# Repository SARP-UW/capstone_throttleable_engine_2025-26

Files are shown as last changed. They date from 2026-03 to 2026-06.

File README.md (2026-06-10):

# capstone_throttleable_engine_2025-26

2025-2026 SARP Capstone Project — a throttleable ethanol / nitrous engine injector testbed.

This repository includes:
- **software** (`software/`) — Python DAQ, valve actuation, throttle control, and web GUI
- **hardware** (`hardware/`) — KiCAD PCB design for DAQ, valve actuation, and servo control
- **analysis** (`analysis/`) — Thermal, structural, and control system analysis 

---

## Software

**Package:** `deep-thrott-code` v0.1.0  
**Requires:** Python ≥ 3.10

### Installation

```bash
pip install -e .
```

### Running the GUI

The system is split into two servers:

| Server | Default address | Role |
|---|---|---|
| **Backend** | `http://0.0.0.0:6001` | DAQ, valve control, F3C sequencer, Socket.IO |
| **GUI** | `http://127.0.0.1:5000` | Serves the web frontend only |

When you open the GUI in a browser, the frontend JS automatically connects to the backend via Socket.IO on port 6001 (same host, different port). The backend streams live sensor data at ~10 Hz and receives commands (valve actuation, sequence control, start/stop logging) from the GUI.

**Running both on the same machine:**

```bash
# Terminal 1 — start the backend
python -m deep_thrott_code.main --host 0.0.0.0 --port 6001

# Terminal 2 — start the GUI server
python -m deep_thrott_code.gui.run_gui --host 0.0.0.0 --port 5000
```

Once the server is running, open any browser on the same network and navigate to:

```
http://<host-ip>:5000
```

If running locally, just go to `http://localhost:5000` or `http://127.0.0.1:5000`.  
If running on a Raspberry Pi, use the Pi's IP address: `http://192.168.x.x:5000`.

**Running backend on a Pi, GUI on your laptop:**

```bash
# On the Pi
python -m deep_thrott_code.main --host 0.0.0.0 --port 6001

# On your laptop (point GUI at the Pi's IP)
python -m deep_thrott_code.gui --backend http://192.168.x.x:6001 --host 127.0.0.1 --port 5000
```

Then open `http://localhost:5000` on your laptop.

**What you see in the browser:**

The GUI is a single-page app with:
- **Line control tabs** — PID diagrams with live valve state and pressure readouts for ethanol and nitrous lines
- **DAQ tabs** — 18 real-time sensor plots (auto-scaled, 300-point history)
- **Sequence panel** — step-by-step fire sequence tracking with manual step execution
- **Settings** — simulation toggle, test selection (hotfire / cold flow), sensor selection, theme

**CLI flags (main backend):**

| Flag | Description |
|---|---|
| `--host` | Bind host (default `0.0.0.0`) |
| `--port` | Bind port (default `6001`) |
| `--simulation` | Run without hardware (sensor simulation) |
| `--no-gui-server` | Start backend only, no Flask server |
| `--autostart` | Automatically start DAQ on launch |
| `--no-sequencer` | Disable the F3C fire sequencer |
| `--debug` | Enable Flask debug mode |

### Structure

```
software/src/deep_thrott_code/
├── main.py               # Entry point
├── backend/              # App factory, GUI command handlers, DAQ runtime
├── gui/                  # Flask + Socket.IO web interface (routes, sockets)
├── daq/                  # Data acquisition — ADC drivers and sensor interfaces
├── f3c/                  # Sequencer and valve control
├── control/              # PID throttle controller and servo characterization
└── config/               # Default configuration files
```

**Utility scripts** (`software/scripts/`):
- `hotfire.py` — Hotfire sequence runner
- `calibrate_sensors.py` — Sensor calibration
- `plot_daq_csv.py` — Plot data from DAQ CSV logs
- `adc_smoke_test.py` — ADC hardware smoke test

### Dependencies

| Package | Purpose |
|---|---|
| Flask, Flask-SocketIO | Web GUI server |
| NumPy, SciPy | Numerical computation |
| PyYAML | Configuration parsing |
| PySerial | Serial communication |
| Matplotlib | Data visualization |
| RPi.GPIO, pigpio, spidev | GPIO and SPI (Linux/RPi only) |
| eventlet *(optional)* | Async server mode |

---

## Hardware

KiCAD project located in `hardware/cda-pcb/`. Includes schematic, PCB layout, Gerber files, and custom symbols/footprints.

---

## Analysis

- `analysis/control_dev/` — Control system models (MATLAB and Python)
- `analysis/engine_dev/` — Structural analysis (Python, based on GRACE methodology)

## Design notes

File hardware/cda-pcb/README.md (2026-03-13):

# High-Precision Raspberry Pi DAQ Board

A custom Data Acquisition (DAQ) hat designed for the Raspberry Pi. This board interfaces with industrial sensors (RTDs, Load Cells, Pressure Transducers) to log and display live data with high precision.

The system features a robust, low-noise power architecture that manages 24VDC input to power the sensors, the precision analog circuitry, and the Raspberry Pi itself. It utilizes dual 24-bit ADCs communicating over SPI for high-resolution signal digitization.

## Features

* **Multi-Sensor Interface:** Three 15-position D-sub connectors for attaching RTDs, Load Cells, and Pressure Transducers.
* **Input Protection:** Every signal line is protected by TVS diode arrays to guard against ESD and surge events.
* **High-Resolution Sampling:** Dual 24-bit ADCs transmit data via SPI to the Raspberry Pi.
* **Low-Noise Power Architecture:**
    * Accepts 24 VDC input.
    * On-board Buck converters for high-efficiency voltage step-down.
    * LDOs and precision voltage references ensure clean power rails for the ADCs and sensors.
    * High-current supply dedicated to the Raspberry Pi.
* **Compact Design:** PCB fits within a 10cm x 10cm footprint to minimize manufacturing costs.

### 3D Rendering
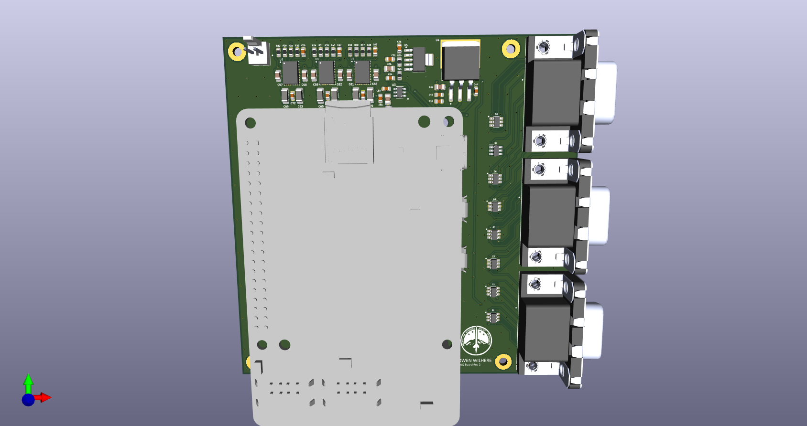
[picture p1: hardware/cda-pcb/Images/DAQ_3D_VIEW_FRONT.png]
Business Card Front


### Layout View
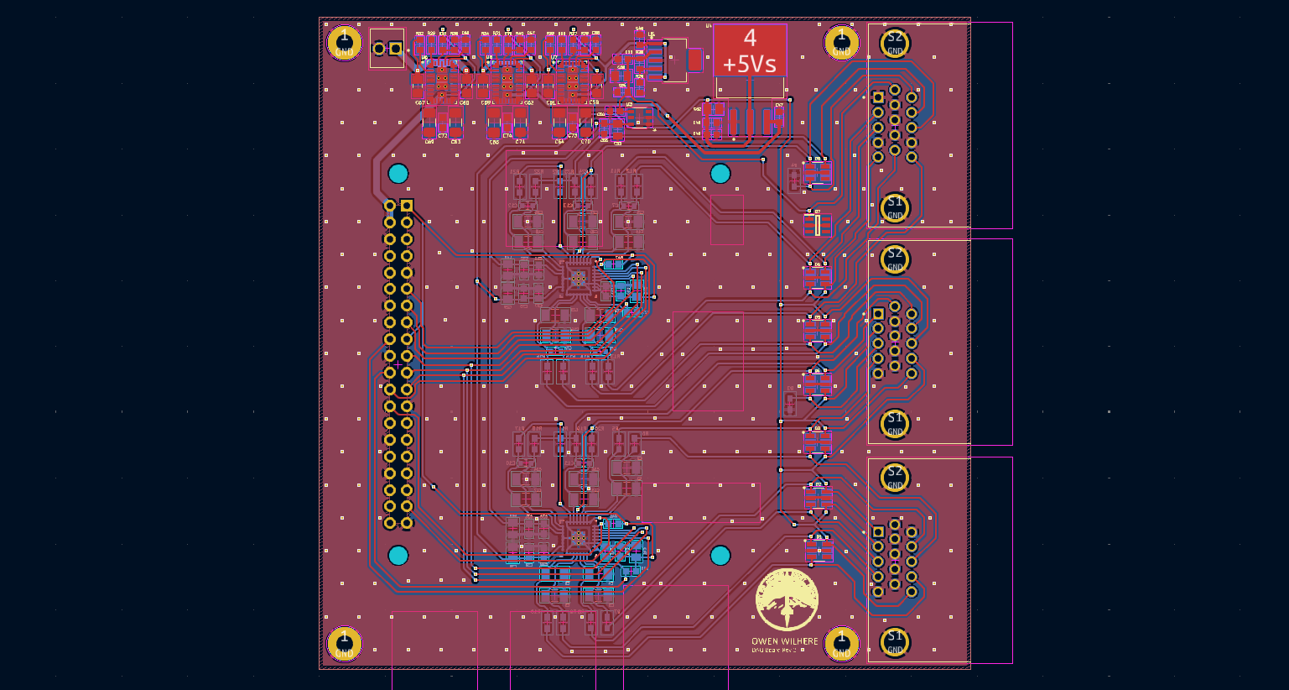
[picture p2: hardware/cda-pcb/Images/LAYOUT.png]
PCB Layout


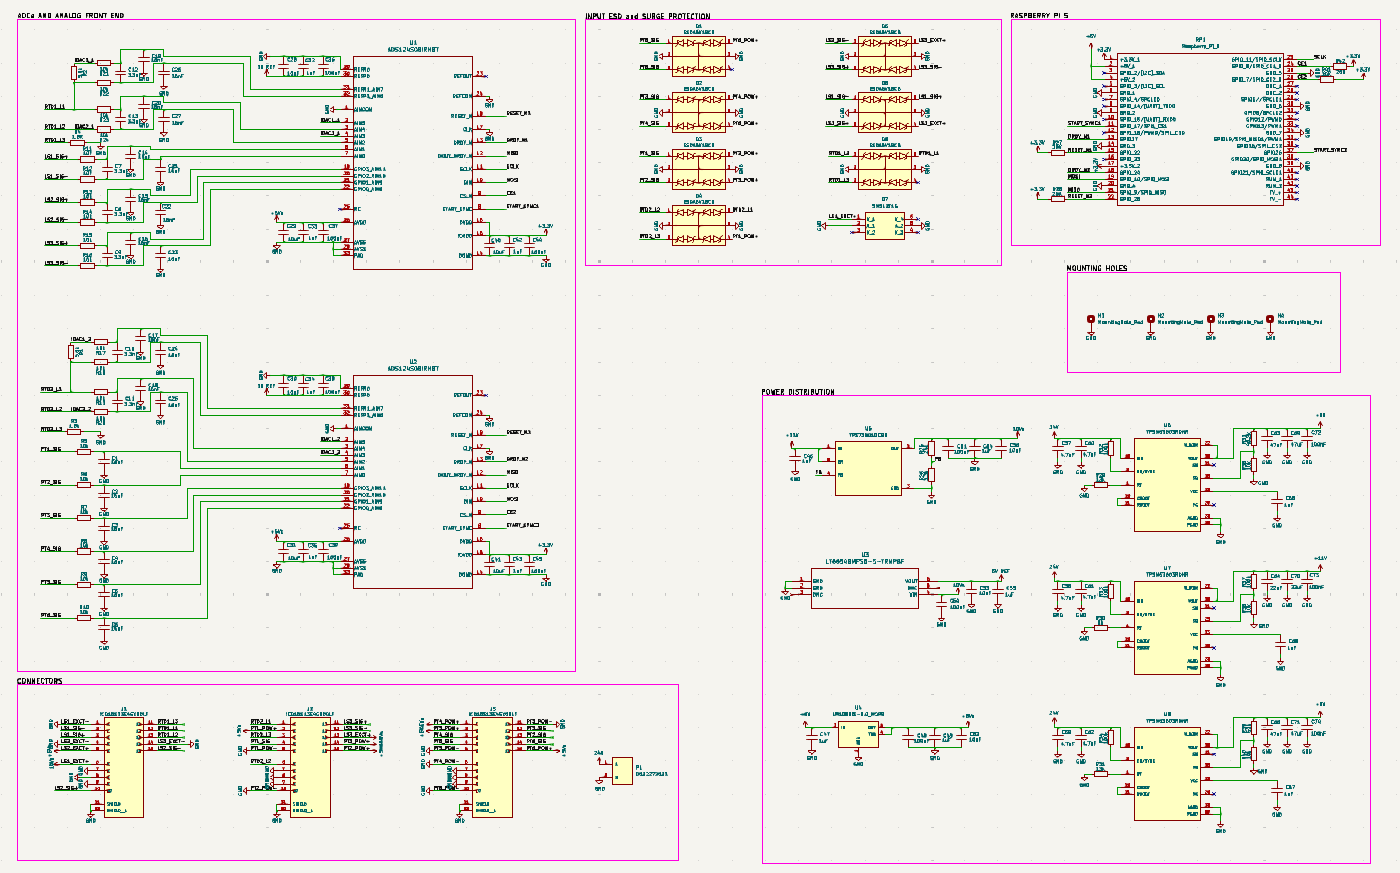
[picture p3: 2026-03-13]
hardware/cda-pcb/Images/SCHEMATIC.png

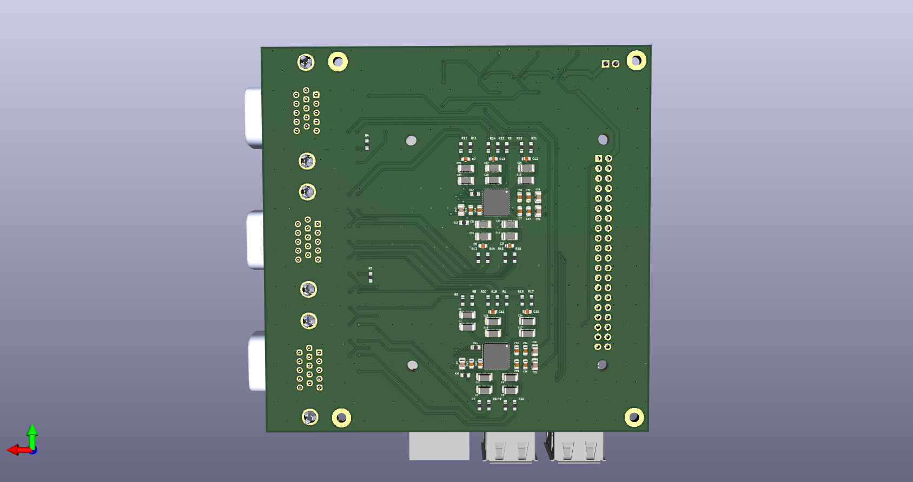
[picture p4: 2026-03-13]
hardware/cda-pcb/Images/DAQ_3D_VIEW_BACK.png

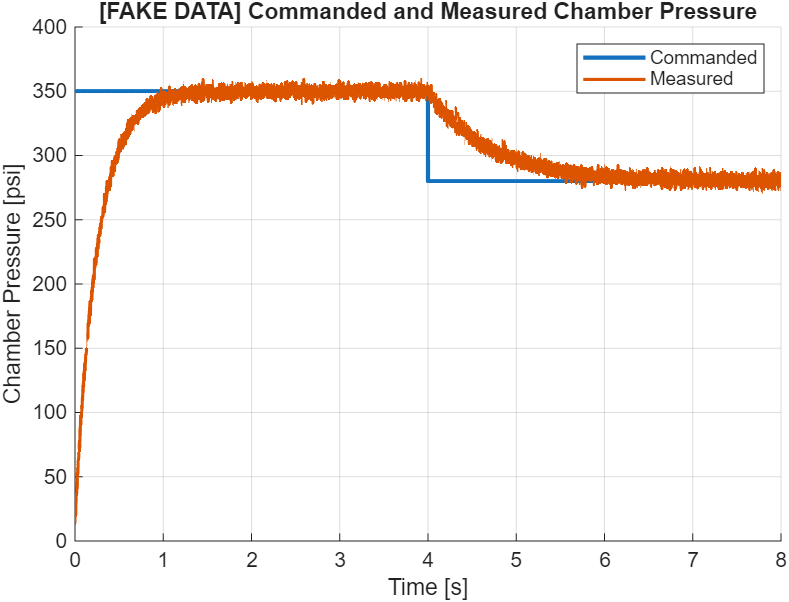
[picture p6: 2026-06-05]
analysis/control_dev/fakedata_conops.png

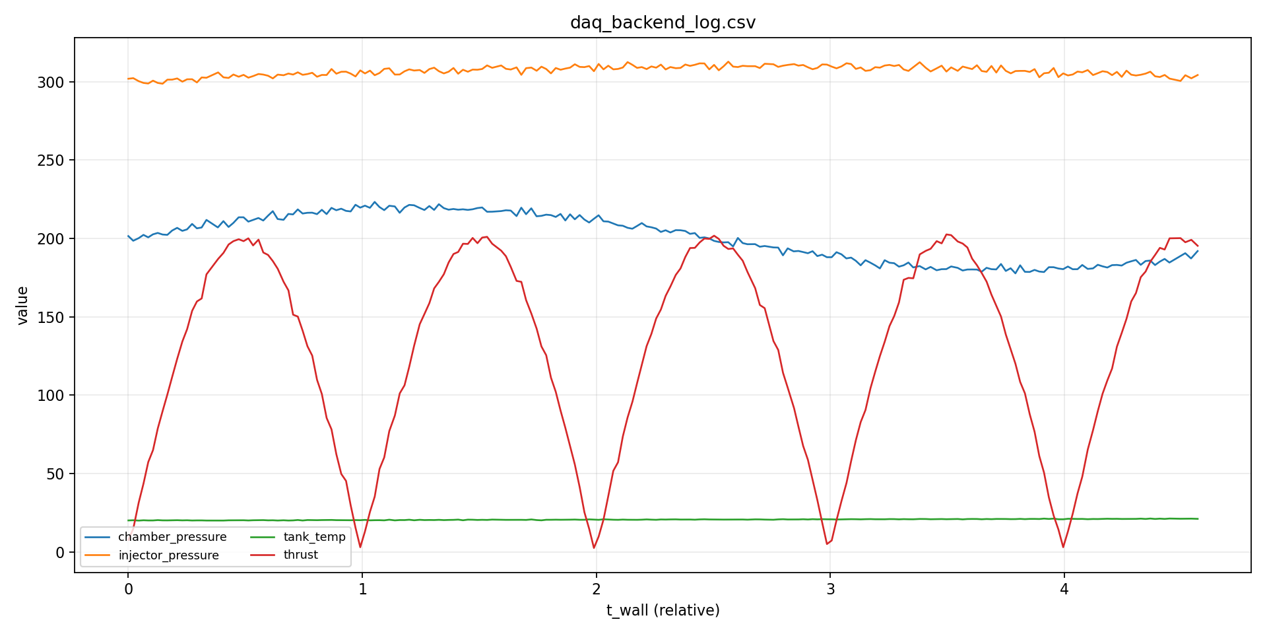
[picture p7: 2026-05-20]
analysis/daq_plot.png

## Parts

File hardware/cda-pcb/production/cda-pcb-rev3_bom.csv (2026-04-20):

Designator | Footprint | Quantity | Value | LCSC Part #
C1, C14, C15, C16, C17, C18, C19, C2, C20, C21, C22, C23, C24, C25, C26, C27, C3, C4, C5, C6, C75, C76, C77, C78, C80, C83, C96, C97, C98, C99 | CAPC3216X95N | 30 | 16nF
C10, C11, C12, C13, C7, C8, C85, C86, C9 | 0603 | 9 | 3.3nF
C28, C29, C30, C31, C40, C41, C52, C53, C56, C87, C88, C93 | CAPC2012X145N | 12 | 10uF
C32, C33, C34, C35, C42, C43, C46, C47, C49, C54, C55, C66, C67, C68, C89, C90, C94 | CAPC1608X94N | 17 | 1uF
C36, C37, C38, C39, C44, C45, C48, C50, C51, C72, C73, C74, C84, C91, C92, C95 | CAPC1608X97N | 16 | 100nF
C57, C58, C59, C60, C61, C62 | 0805 | 6 | 4.7uF
C63, C65, C69, C71 | 1206 | 4 | 47uF
C64, C70 | 1206 | 2 | 22uF
D1, D10, D12, D2, D3, D4, D5, D6, D7, D8, D9 | SOT95P280X145-6N | 11 | ESDA6V1BC6
D11 | SOT95P275X110-6N | 1 | SMS12T1G
D13, D14, D15 | 0805 | 3 | LED
H1, H2, H3, H4 | MountingHole_2.5mm_Pad | 4 | MountingHole_Pad
J1, J2, J3, J4 | AMPHENOL_ICD15S13E4GX00LF | 4 | ICD15S13E4GX00LF
J5 | PinHeader_1x06_P2.54mm_Vertical | 1 | Conn_01x06
P1 | CONN_SD-43650-010_02_MOL | 1 | 436500227
R1, R2, R49, R56 | 0603 | 4 | 5.6k
R10, R11, R12, R13, R14, R15, R16, R17, R18, R19, R20, R21, R22, R23, R24, R44, R45, R46, R47, R48, R5, R55, R58, R59, R6, R60, R61, R7, R8, R9 | 0603 | 30 | 10k
R25, R29, R31 | RESC1508X50N | 3 | 13k
R26 | RESC1508X50N | 1 | 1.8k
R27, R28, R41, R42, R43, R51, R53, R54 | RESC1508X50N | 8 | 20K
R3, R4, R57, R63, R64 | 0603 | 5 | 1.8k
R30 | RESC1508X50N | 1 | 8k
R32, R33, R34, R37 | RESC1508X50N | 4 | 100k
R35 | RESC1508X50N | 1 | 40.2k
R36, R38, R40, R52 | RESC1508X50N | 4 | 10k
R39 | RESC1508X50N | 1 | 50k
RP1 | raspberrypi_2_3 | 1 | Raspberry_Pi_4
U1, U2, U3 | QFN50P500X500X100-33N | 3 | ADS124S08IRHBT
U10 | RGY14_2P05X2P05 | 1 | SN74AHCT125RGYR
U4 | TSOT-23_S6_LIT | 1 | LT6654BMPS6-5-TRMPBF
U5 | TO254P1524X483-4N | 1 | LM1086IS-5.0_NOPB
U6 | SOT127P706X180-6N | 1 | TPS73801DCQR
U7, U8, U9 | CONV_TPSM63602RDHR | 3 | TPSM63603RDHR

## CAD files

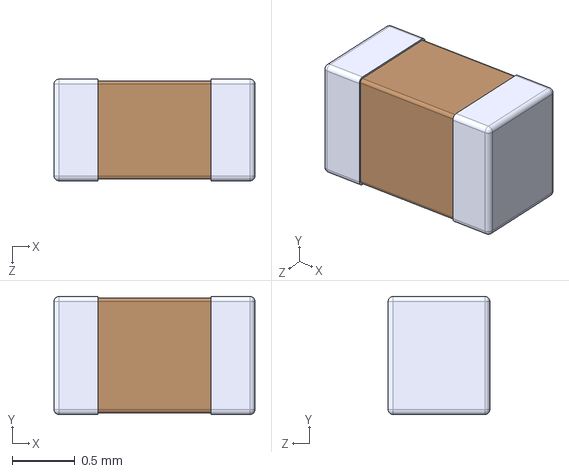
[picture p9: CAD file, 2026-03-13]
hardware/cda-pcb/symbols_and_footprints/0603YC105JAT2A/CAPC1608X94N.step
1.60 x 0.94 x 0.81 mm

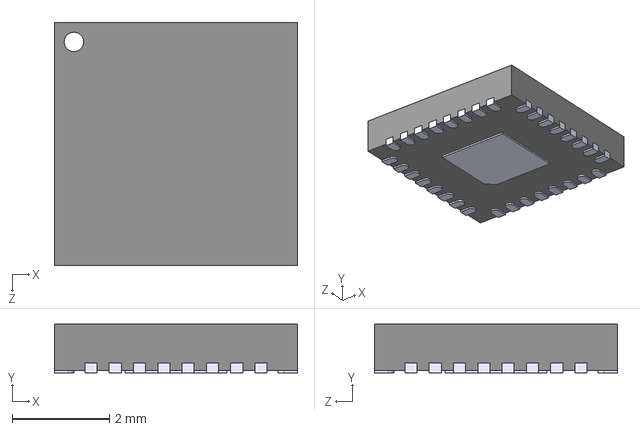
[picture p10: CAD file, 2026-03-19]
hardware/cda-pcb/symbols_and_footprints/ADS124S08IRHBT/ADS124S08IRHBT.step
5.00 x 1.00 x 5.00 mm

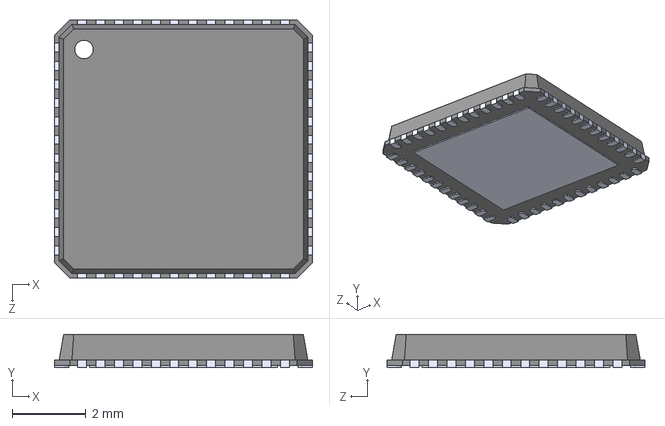
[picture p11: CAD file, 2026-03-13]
hardware/cda-pcb/symbols_and_footprints/ADS1258IRTCT/ADS1258IRTCT.step
7.00 x 0.9 x 7.00 mm

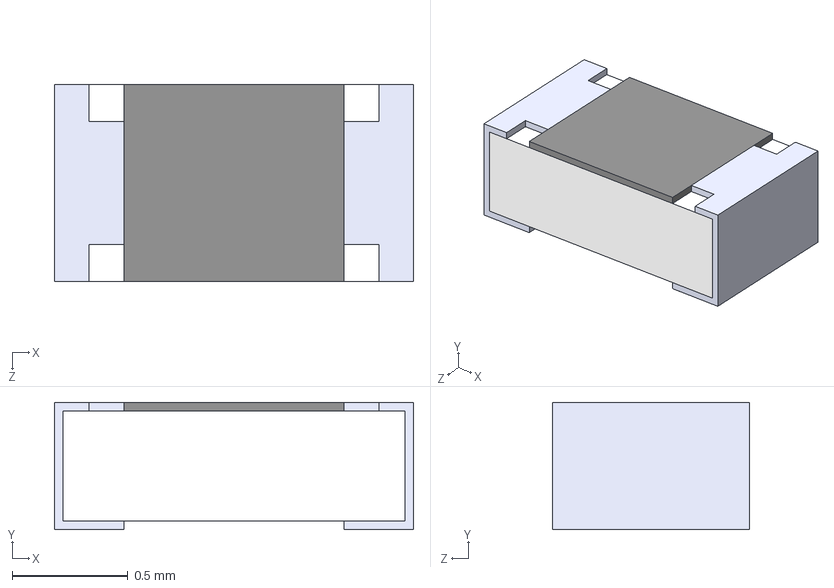
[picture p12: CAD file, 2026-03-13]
hardware/cda-pcb/symbols_and_footprints/CRCW0603100KFKEA/CRCW0603100KFKEA.step
1.55 x 0.55 x 0.85 mm

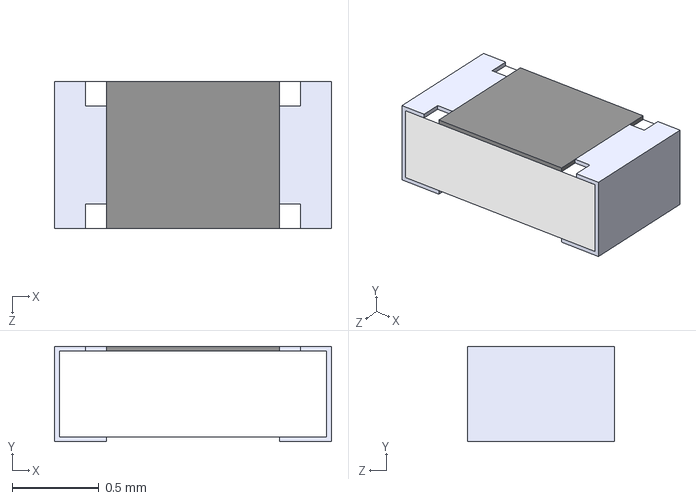
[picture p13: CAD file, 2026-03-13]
hardware/cda-pcb/symbols_and_footprints/CRCW0603120RFKEAHP/CRCW0603120RFKEAHP.step
1.60 x 0.55 x 0.85 mm

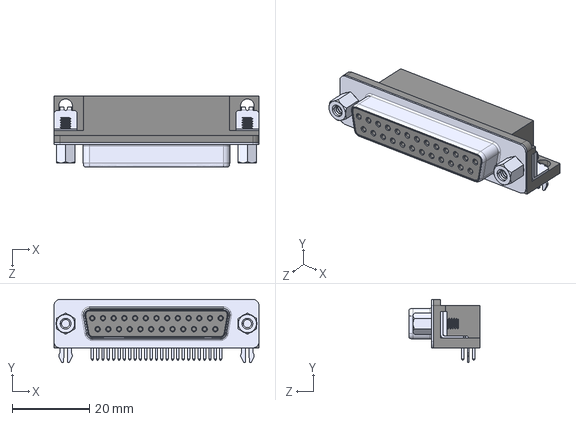
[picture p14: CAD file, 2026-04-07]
hardware/cda-pcb/symbols_and_footprints/DB25_SL_25/DB25-SL-25.step
53.0 x 16.3 x 18.3 mm

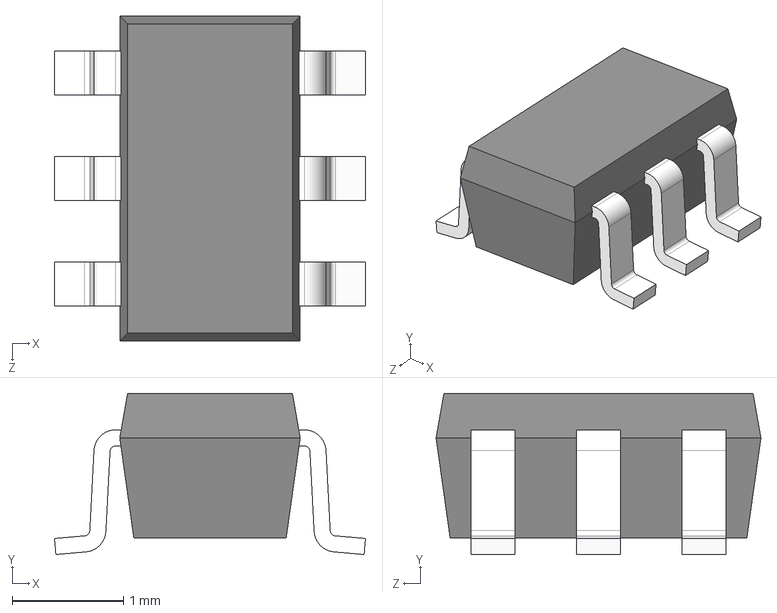
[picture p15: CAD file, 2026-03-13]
hardware/cda-pcb/symbols_and_footprints/ESDA6V1BC6/ESDA6V1BC6.step
2.80 x 1.45 x 2.92 mm

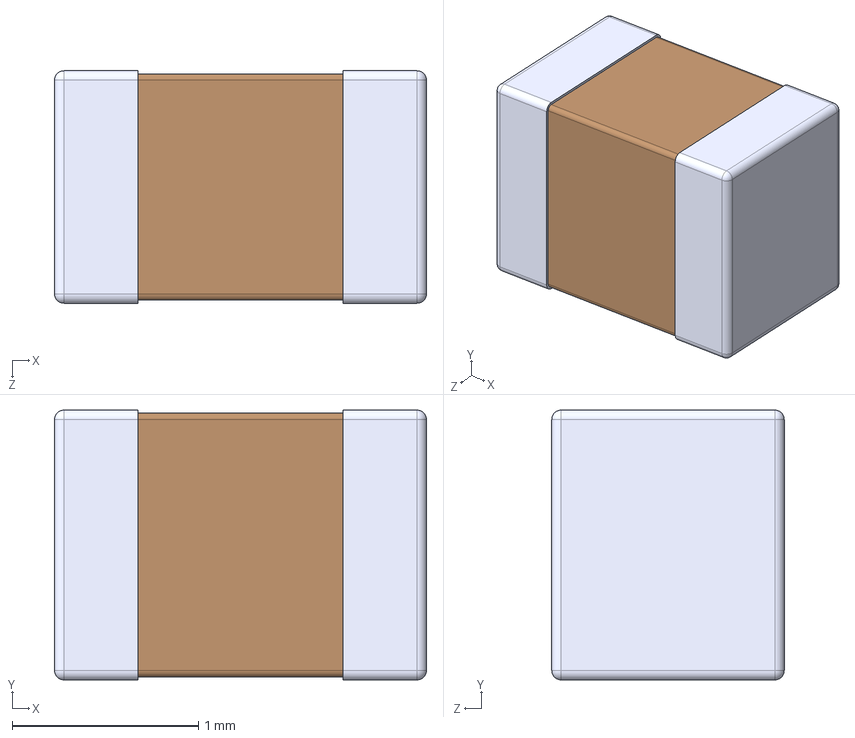
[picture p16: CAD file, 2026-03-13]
hardware/cda-pcb/symbols_and_footprints/GRM21BC71E106KE11L/GRM21BC71E106KE11L.step
2.00 x 1.45 x 1.25 mm

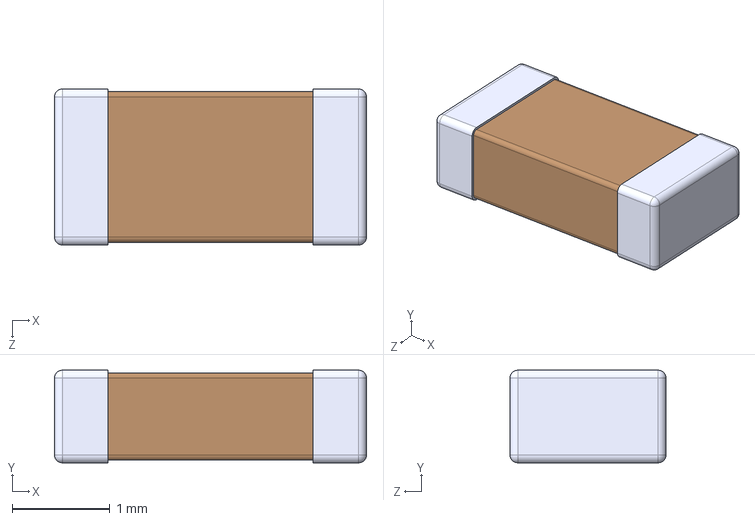
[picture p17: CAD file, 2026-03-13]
hardware/cda-pcb/symbols_and_footprints/GRM3195C2A163JA01D/CAPC3216X95N.step
3.20 x 0.95 x 1.60 mm

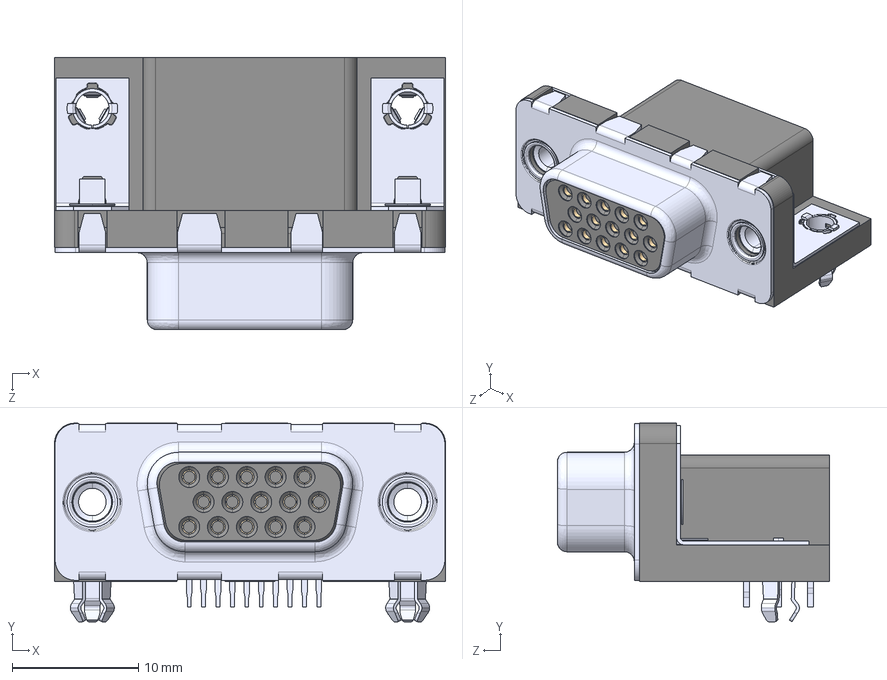
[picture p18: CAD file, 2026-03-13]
hardware/cda-pcb/symbols_and_footprints/ICD15S13/ICD15S13E4GX00LF.step
31.0 x 15.7 x 21.6 mm

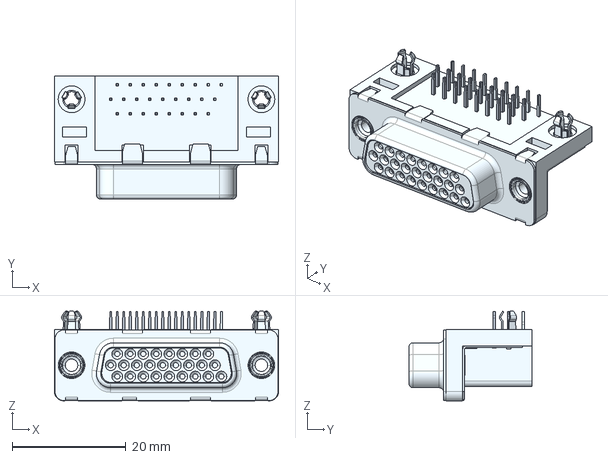
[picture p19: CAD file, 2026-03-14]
hardware/cda-pcb/symbols_and_footprints/ICD26S13E4GX00LF/ICD26S13E4GX00LF.step
39.3 x 21.6 x 15.8 mm

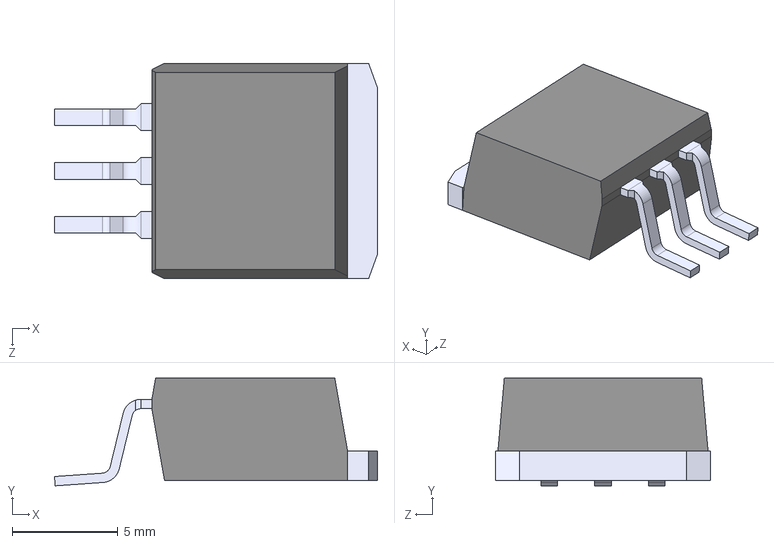
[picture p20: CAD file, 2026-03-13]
hardware/cda-pcb/symbols_and_footprints/LM1086IS-5.0/LM1086IS-5.0.step
15.2 x 5.08 x 10.2 mm

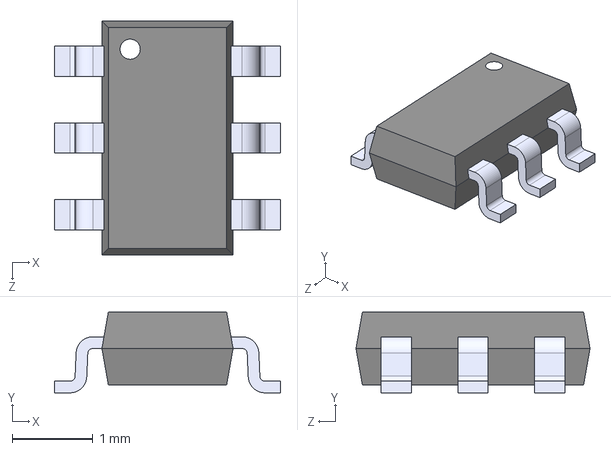
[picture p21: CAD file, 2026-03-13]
hardware/cda-pcb/symbols_and_footprints/LT6654BMPS6_5_TRMPBF/LT6654BMPS6-5#TRPBF.STEP
2.80 x 1.00 x 2.90 mm

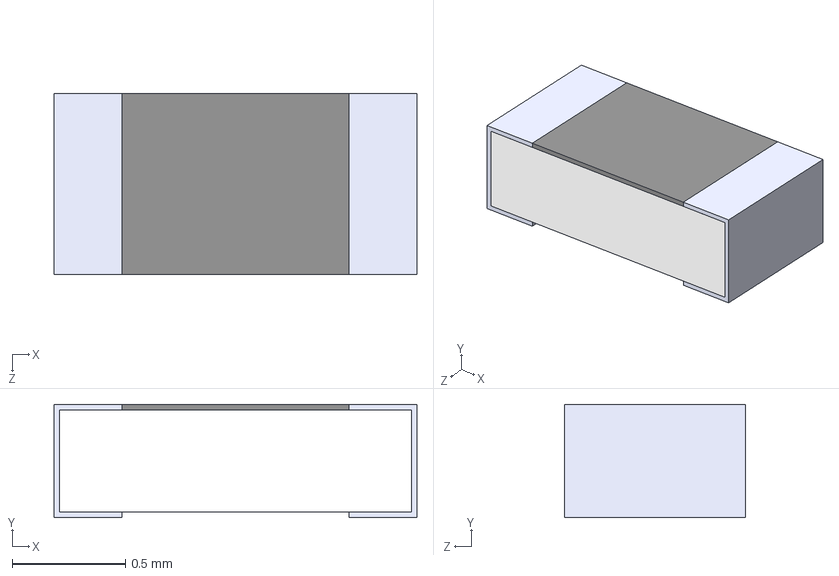
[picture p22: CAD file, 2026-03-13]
hardware/cda-pcb/symbols_and_footprints/RG1608N-102-D-T5/RG1608N-102-D-T5.step
1.60 x 0.5 x 0.8 mm

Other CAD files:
hardware/cda-pcb/symbols_and_footprints/SEN-13879/SEN-13879.step
hardware/cda-pcb/symbols_and_footprints/SMST12T1G/SMS12T1G.STEP
hardware/cda-pcb/symbols_and_footprints/TPSM63602RDHDR/TPSM63602RDHR.step
hardware/cda-pcb/symbols_and_footprints/0022272021/0022272021.step
hardware/cda-pcb/symbols_and_footprints/10090929-S154VLF/10090929-S154VLF.step
hardware/cda-pcb/symbols_and_footprints/436500227/436500227.stp
hardware/cda-pcb/symbols_and_footprints/TPS73801/TPS73801DCQR.step
hardware/cda-pcb/symbols_and_footprints/VJ0603Y104JXXAC/VJ0603Y104JXXAC.step

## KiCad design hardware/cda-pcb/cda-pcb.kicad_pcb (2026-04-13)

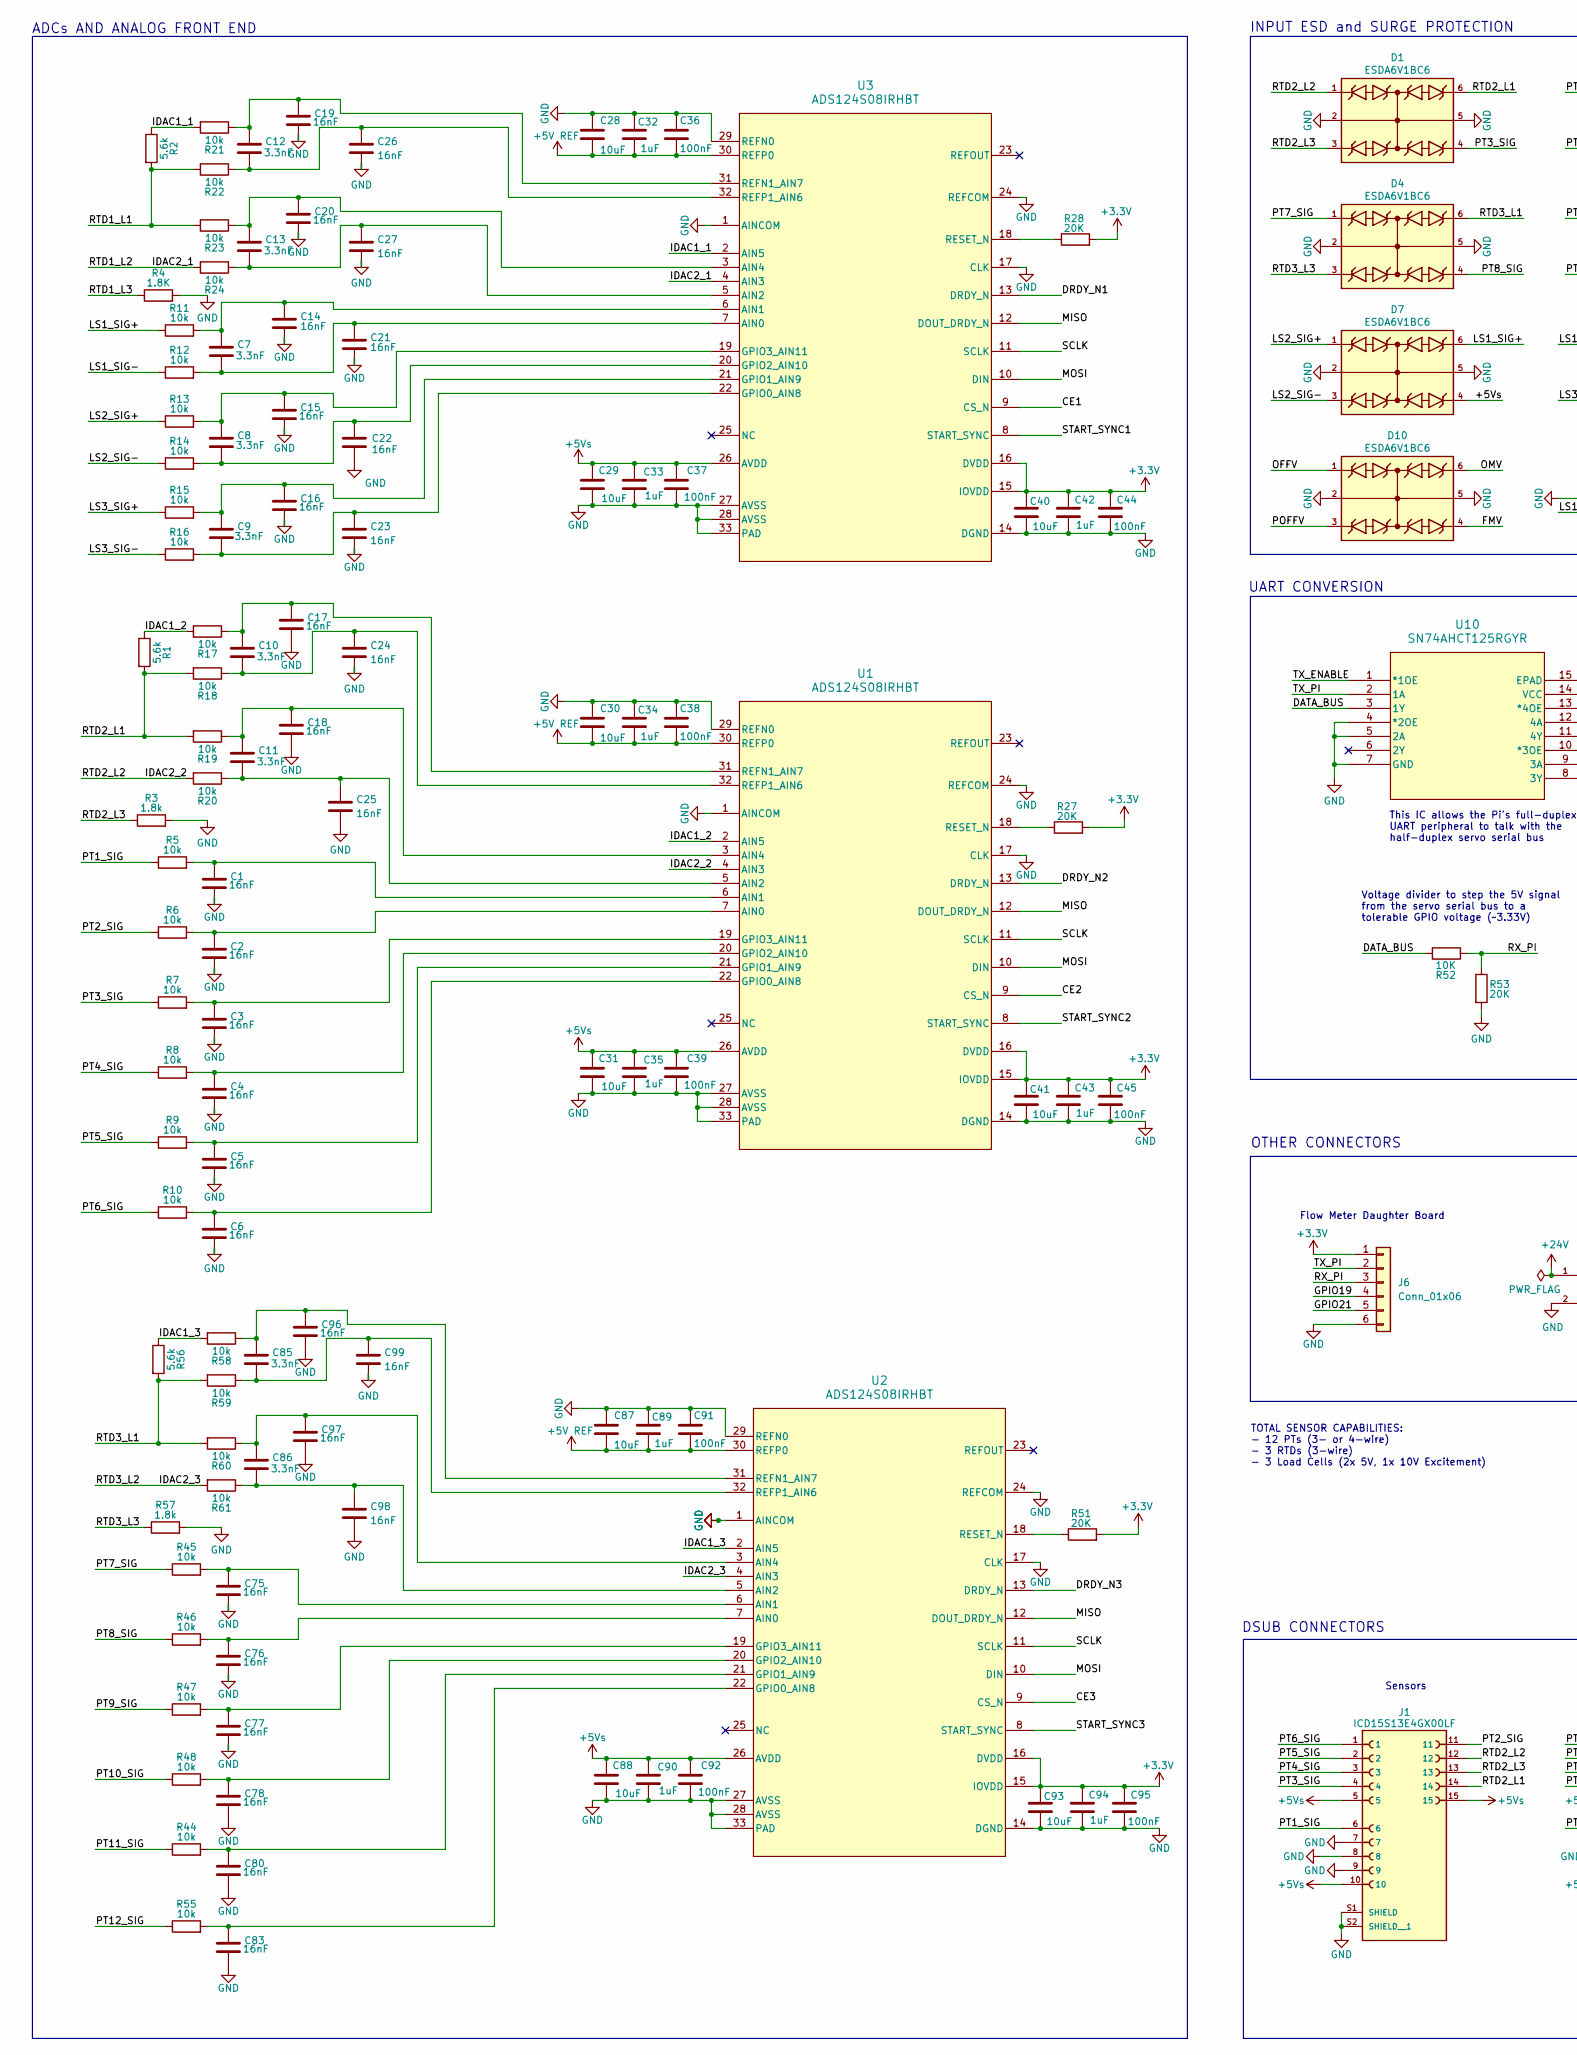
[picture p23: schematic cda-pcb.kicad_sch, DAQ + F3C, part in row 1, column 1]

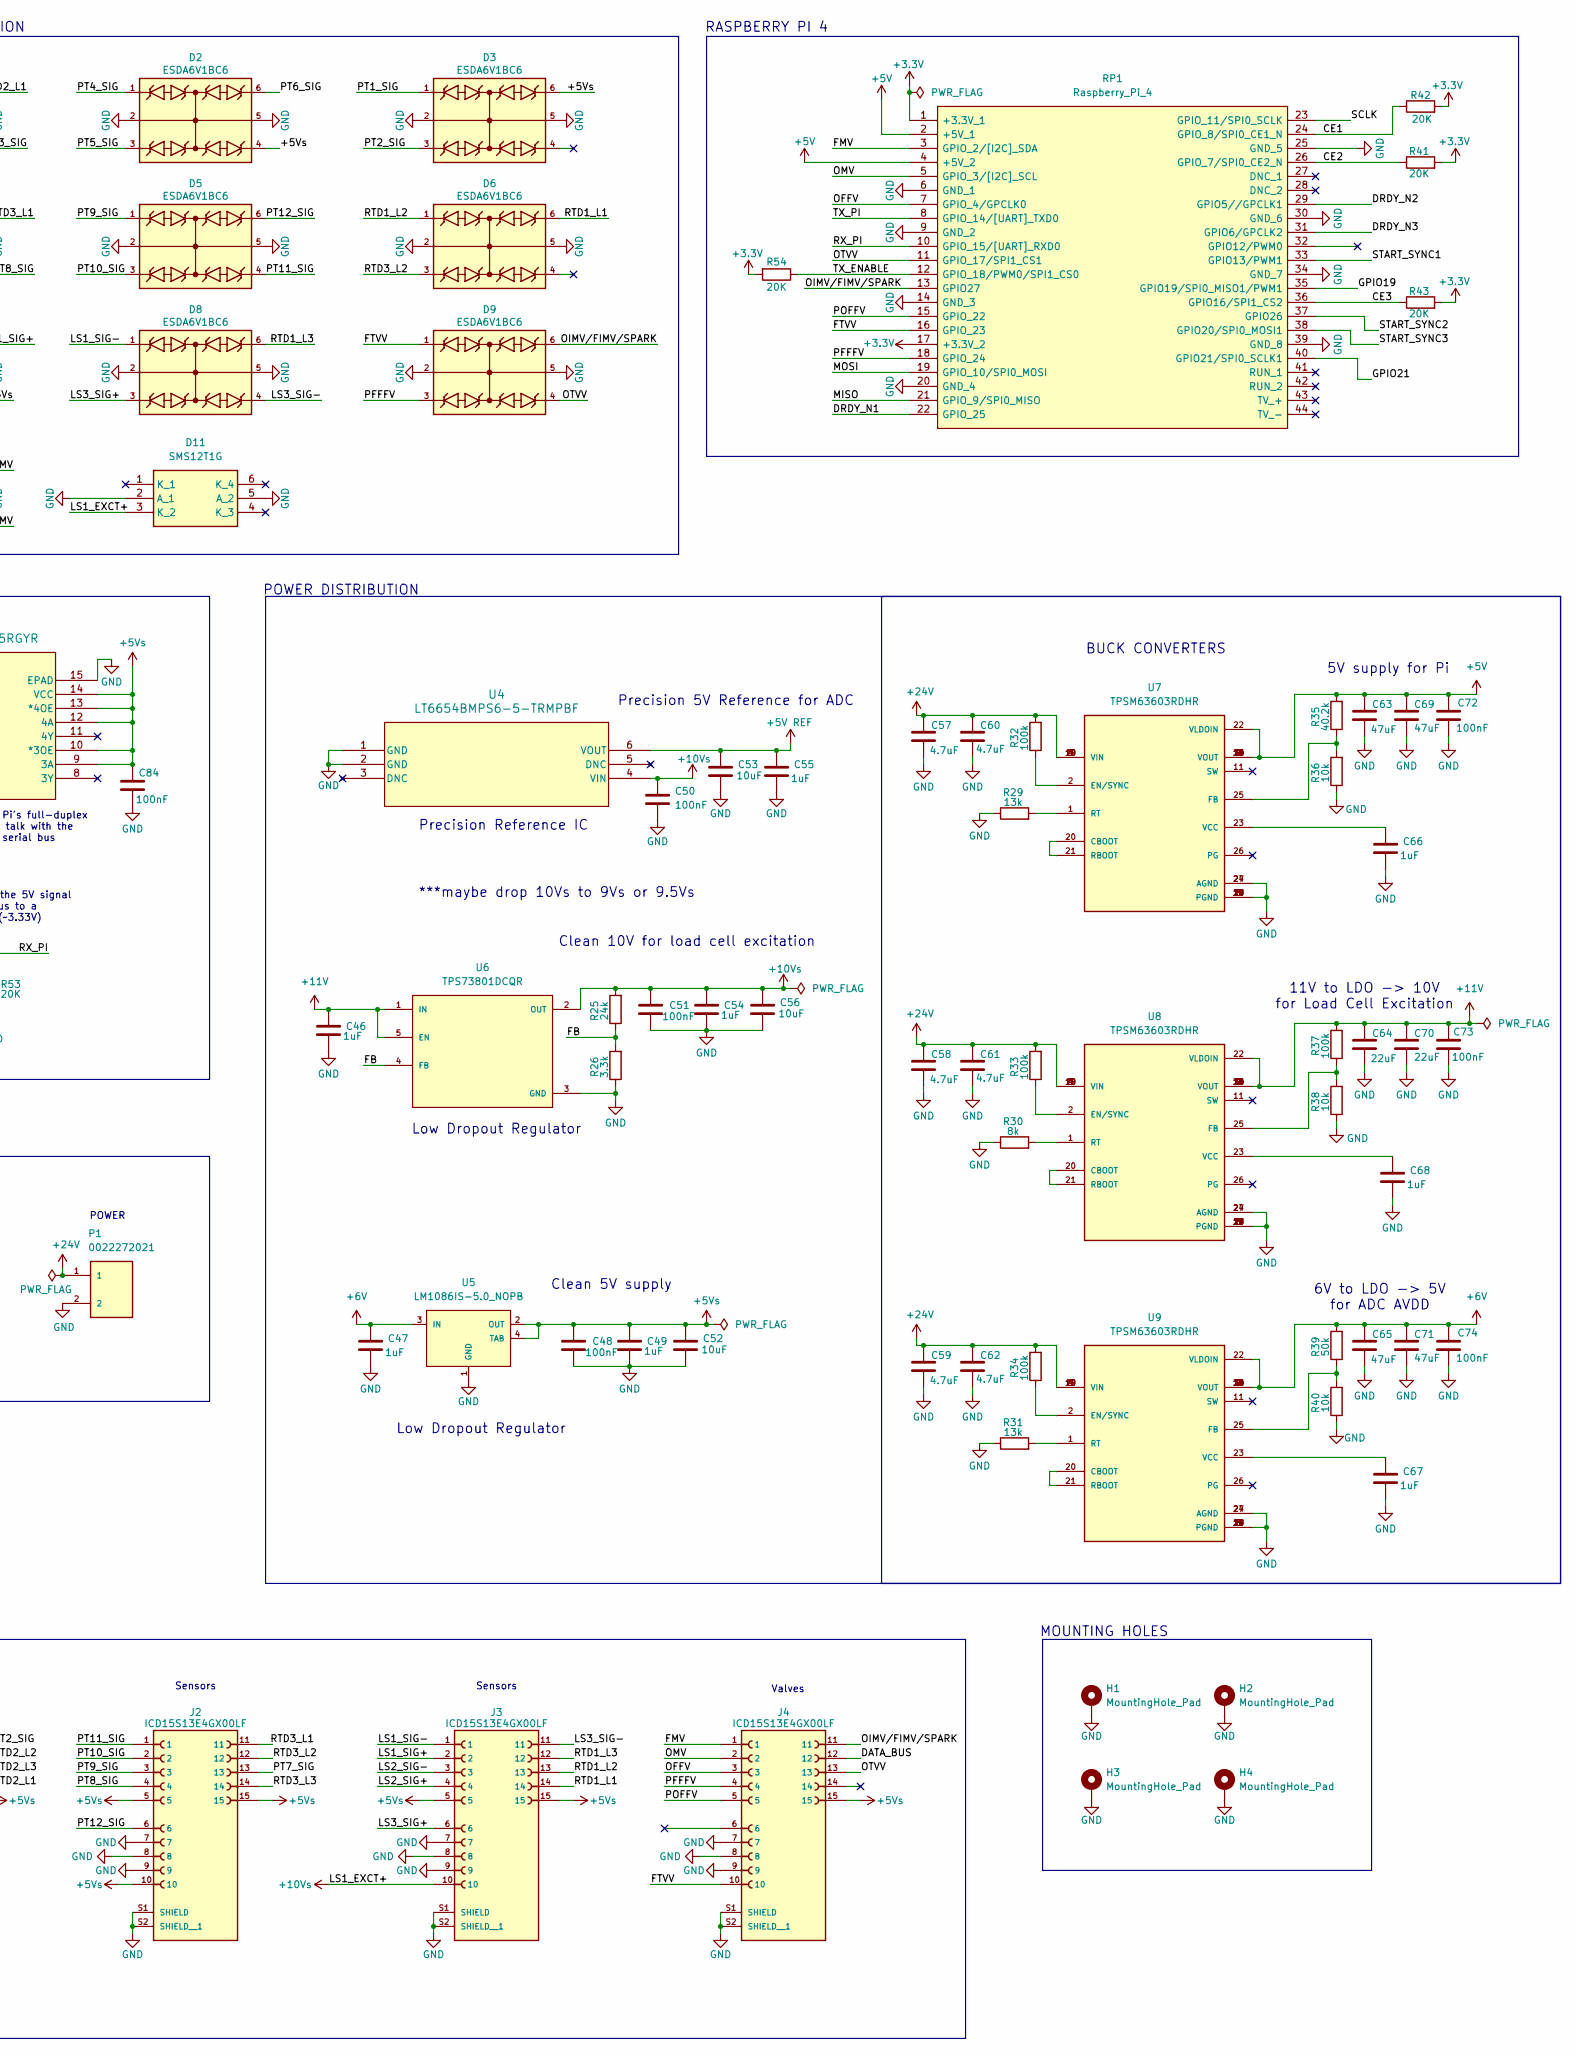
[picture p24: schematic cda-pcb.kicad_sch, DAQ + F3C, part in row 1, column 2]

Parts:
C1, C2, C3, C4, C5, C6, C14, C15, C16, C17, C18, C19, C20, C21, C22, C23, C24, C25, C26, C27, C75, C76, C77, C78, C80, C83, C96, C97, C98, C99: 16nF; CAPC3216X95N
C7, C8, C9, C10, C11, C12, C13, C85, C86: 3.3nF; C_0603_1608Metric_Pad1.08x0.95mm_HandSolder
C28, C29, C30, C31, C40, C41, C52, C53, C56, C87, C88, C93: 10uF; CAPC2012X145N
C32, C33, C34, C35, C42, C43, C46, C47, C49, C54, C55, C66, C67, C68, C89, C90, C94: 1uF; CAPC1608X94N
C36, C37, C38, C39, C44, C45, C48, C50, C51, C72, C73, C74, C84, C91, C92, C95: 100nF; CAPC1608X97N
C57, C58, C59, C60, C61, C62: 4.7uF; C_0805_2012Metric_Pad1.18x1.45mm_HandSolder
C63, C65, C69, C71: 47uF; L_1206_3216Metric_Pad1.42x1.75mm_HandSolder
C64, C70: 22uF; L_1206_3216Metric_Pad1.42x1.75mm_HandSolder
D1, D2, D3, D4, D5, D6, D7, D8, D9, D10: ESDA6V1BC6; SOT95P280X145-6N; PARTREV 2
D11: SMS12T1G; SOT95P275X110-6N; Manufacturer_Part_Number SMS12T1G; Mouser Part Number 863-SMS12T1G
H1, H2, H3, H4: MountingHole_Pad; MountingHole_2.5mm_Pad
J1, J2, J3, J4: ICD15S13E4GX00LF; AMPHENOL_ICD15S13E4GX00LF; PARTREV G
J6: Conn_01x06; PinHeader_1x06_P2.54mm_Vertical
P1: 0022272021; MOLEX_0022272021
R1, R2, R56: 5.6k; R_0603_1608Metric
R3, R57: 1.8k; R_0603_1608Metric
R4: 1.8K; R_0603_1608Metric
R5, R6, R7, R8, R9, R10, R11, R12, R13, R14, R15, R16, R17, R18, R19, R20, R21, R22, R23, R24, R44, R45, R46, R47, R48, R55, R58, R59, R60, R61: 10k; R_0603_1608Metric
R25: 24k; RESC1508X50N
R26: 3.3k; RESC1508X50N
R27, R28, R41, R42, R43, R51, R53, R54: 20K; RESC1508X50N
R29, R31: 13k; RESC1508X50N
R30: 8k; RESC1508X50N
R32, R33, R34, R37: 100k; RESC1508X50N
R35: 40.2k; RESC1508X50N
R36, R38, R40: 10k; RESC1508X50N
R39: 50k; RESC1508X50N
R52: 10K; RESC1508X50N
RP1: Raspberry_Pi_4; raspberrypi_2_3; Manufacturer_Part_Number Raspberry Pi 2 or 3
U1, U2: ADS124S08IRHBT; QFN50P500X500X100-33N
U3: ADS124S08IRHBT; RHB0032M
U4: LT6654BMPS6-5-TRMPBF; TSOT-23_S6_LIT
U5: LM1086IS-5.0_NOPB; TO254P1524X483-4N
U6: TPS73801DCQR; SOT127P706X180-6N
U7, U8, U9: TPSM63603RDHR; CONV_TPSM63602RDHR; PARTREV April 2022
U10: SN74AHCT125RGYR; RGY14_2P05X2P05

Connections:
+3.3V: C40.1, C41.1, C42.1, C43.1, C44.1, C45.1, C93.1, C94.1, C95.1, J6.1, R27.2, R28.2, R41.2, R42.2, R43.2, R51.2, R54.2, RP1.1 (+3.3V_1), RP1.17 (+3.3V_2), U1.15 (IOVDD), U1.16 (DVDD), U2.15 (IOVDD), U2.16 (DVDD), U3.15 (IOVDD), U3.16 (DVDD)
+5V: C63.2, C69.2, C72.1, R35.2, RP1.2 (+5V_1), RP1.4 (+5V_2), U7.7 (VOUT), U7.8 (VOUT), U7.9 (VOUT), U7.10 (VOUT), U7.12 (VOUT), U7.13 (VOUT), U7.14 (VOUT), U7.15 (VOUT), U7.22 (VLDOIN), U7.30 (VOUT)
+5V REF: C28.2, C30.2, C32.2, C34.2, C36.2, C38.2, C53.1, C55.1, C87.2, C89.2, C91.2, U1.30 (REFP0), U2.30 (REFP0), U3.30 (REFP0), U4.6 (VOUT)
+5Vs: C29.1, C31.1, C33.1, C35.1, C37.1, C39.1, C48.1, C49.1, C52.1, C84.1, C88.1, C90.1, C92.1, D2.4, D3.6, D7.4, J1.5, J1.10, J1.15, J2.5, J2.10, J2.15, J3.5, J3.15, J4.15, U1.26 (AVDD), U2.26 (AVDD), U3.26 (AVDD), U5.2 (OUT), U5.4 (TAB), U10.9 (3A), U10.10 (*3OE), U10.12 (4A), U10.13 (*4OE), U10.14 (VCC)
+6V: C47.1, C65.2, C71.2, C74.1, R39.2, U5.3 (IN), U9.7 (VOUT), U9.8 (VOUT), U9.9 (VOUT), U9.10 (VOUT), U9.12 (VOUT), U9.13 (VOUT), U9.14 (VOUT), U9.15 (VOUT), U9.22 (VLDOIN), U9.30 (VOUT), U9.31
+10Vs: C50.1, C51.1, C54.1, C56.1, D11.3 (K_2), J3.10, R25.2, U4.4 (VIN), U6.2 (OUT)
+11V: C46.1, C64.2, C70.2, C73.1, R37.2, U6.1 (IN), U6.5 (EN), U8.7 (VOUT), U8.8 (VOUT), U8.9 (VOUT), U8.10 (VOUT), U8.12 (VOUT), U8.13 (VOUT), U8.14 (VOUT), U8.15 (VOUT), U8.22 (VLDOIN), U8.30 (VOUT), U8.31
+24V: C57.2, C58.2, C59.2, C60.2, C61.2, C62.2, P1.1, R32.2, R33.2, R34.2, U7.3 (VIN), U7.4 (VIN), U7.18 (VIN), U7.19 (VIN), U8.3 (VIN), U8.4 (VIN), U8.18 (VIN), U8.19 (VIN), U9.3 (VIN), U9.4 (VIN), U9.18 (VIN), U9.19 (VIN)
/CE1: R42.1, RP1.24 (GPIO_8/SPI0_CE1_N), U3.9 (CS_N)
/CE2: R41.1, RP1.26 (GPIO_7/SPI0_CE2_N), U1.9 (CS_N)
/CE3: R43.1, RP1.36 (GPIO16/SPI1_CS2), U2.9 (CS_N)
/DATA_BUS: J4.12, R52.2, U10.3 (1Y)
/DRDY_N1: RP1.22 (GPIO_25), U3.13 (DRDY_N)
/DRDY_N2: RP1.29 (GPIO5//GPCLK1), U1.13 (DRDY_N)
/DRDY_N3: RP1.31 (GPIO6/GPCLK2), U2.13 (DRDY_N)
/FB: R25.1, R26.2, U6.4 (FB)
/FMV: D10.4, J4.1, RP1.3 (GPIO_2/[I2C]_SDA)
/FTVV: D9.1, J4.10, RP1.16 (GPIO_23)
/GPIO19: J6.4, RP1.35 (GPIO19/SPI0_MISO1/PWM1)
/GPIO21: J6.5, RP1.40 (GPIO21/SPI0_SCLK1)
/IDAC1_1: R2.1, R21.2, U3.2 (AIN5)
/IDAC1_2: R1.1, R17.2, U1.2 (AIN5)
/IDAC1_3: R56.1, R58.2, U2.2 (AIN5)
/IDAC2_1: D6.1, J3.13, R24.2, U3.4 (AIN3)
/IDAC2_2: D1.1, J1.12, R20.2, U1.4 (AIN3)
/IDAC2_3: D6.3, J2.12, R61.2, U2.4 (AIN3)
/LS1_SIG+: D7.6, J3.2, R11.1
/LS1_SIG-: D8.1, J3.1, R12.1
/LS2_SIG+: D7.1, J3.4, R13.1
/LS2_SIG-: D7.3, J3.3, R14.1
/LS3_SIG+: D8.3, J3.6, R15.1
/LS3_SIG-: D8.4, J3.11, R16.1
/MISO: RP1.21 (GPIO_9/SPI0_MISO), U1.12 (DOUT_DRDY_N), U2.12 (DOUT_DRDY_N), U3.12 (DOUT_DRDY_N)
/MOSI: RP1.19 (GPIO_10/SPI0_MOSI), U1.10 (DIN), U2.10 (DIN), U3.10 (DIN)
/OFFV: D10.1, J4.3, RP1.7 (GPIO_4/GPCLK0)
/OIMV/FIMV/SPARK: D9.6, J4.11, RP1.13 (GPIO27)
/OMV: D10.6, J4.2, RP1.5 (GPIO_3/[I2C]_SCL)
/OTVV: D9.4, J4.13, RP1.11 (GPIO_17/SPI1_CS1)
/PFFFV: D9.3, J4.4, RP1.18 (GPIO_24)
/POFFV: D10.3, J4.5, RP1.15 (GPIO_22)
/PT1_SIG: D3.1, J1.6, R5.1
/PT2_SIG: D3.3, J1.11, R6.1
/PT3_SIG: D1.4, J1.4, R7.1
/PT4_SIG: D2.1, J1.3, R8.1
/PT5_SIG: D2.3, J1.2, R9.1
/PT6_SIG: D2.6, J1.1, R10.1
/PT7_SIG: D4.1, J2.13, R45.1
/PT8_SIG: D4.4, J2.4, R46.1
/PT9_SIG: D5.1, J2.3, R47.1
/PT10_SIG: D5.3, J2.2, R48.1
/PT11_SIG: D5.4, J2.1, R44.1
/PT12_SIG: D5.6, J2.6, R55.1
/RTD1_L1: D6.6, J3.14, R2.2, R22.2, R23.2
/RTD1_L3: D8.6, J3.12, R4.1
/RTD2_L1: D1.6, J1.14, R1.2, R18.2, R19.2
/RTD2_L3: D1.3, J1.13, R3.1
/RTD3_L1: D4.6, J2.11, R56.2, R59.2, R60.2
/RTD3_L3: D4.3, J2.14, R57.1
/RX_PI: J6.3, R52.1, R53.1, RP1.10 (GPIO_15/[UART]_RXD0)
/SCLK: RP1.23 (GPIO_11/SPI0_SCLK), U1.11 (SCLK), U2.11 (SCLK), U3.11 (SCLK)
/START_SYNC1: RP1.33 (GPIO13/PWM1), U3.8 (START_SYNC)
/START_SYNC2: RP1.37 (GPIO26), U1.8 (START_SYNC)
/START_SYNC3: RP1.38 (GPIO20/SPI0_MOSI1), U2.8 (START_SYNC)
/TX_ENABLE: R54.1, RP1.12 (GPIO_18/PWM0/SPI1_CS0), U10.1 (*1OE)
/TX_PI: J6.2, RP1.8 (GPIO_14/[UART]_TXD0), U10.2 (1A)
GND: C1.2, C2.2, C3.2, C4.2, C5.2, C6.2, C14.2, C15.2, C16.2, C17.2, C18.2, C19.2, C20.2, C21.2, C22.2, C23.2, C24.2, C25.2, C26.2, C27.2, C28.1, C29.2, C30.1, C31.2, C32.1, C33.2, C34.1, C35.2, C36.1, C37.2, C38.1, C39.2, C40.2, C41.2, C42.2, C43.2, C44.2, C45.2, C46.2, C47.2, C48.2, C49.2, C50.2, C51.2, C52.2, C53.2, C54.2, C55.2, C56.2, C57.1, C58.1, C59.1, C60.1, C61.1, C62.1, C63.1, C64.1, C65.1, C66.2, C67.2, C68.2, C69.1, C70.1, C71.1, C72.2, C73.2, C74.2, C75.2, C76.2, C77.2, C78.2, C80.2, C83.2, C84.2, C87.1, C88.2, C89.1, C90.2, C91.1, C92.2, C93.2, C94.2, C95.2, C96.2, C97.2, C98.2, C99.2, D1.2, D1.5, D2.2, D2.5, D3.2, D3.5, D4.2, D4.5, D5.2, D5.5, D6.2, D6.5, D7.2, D7.5, D8.2, D8.5, D9.2, D9.5, D10.2, D10.5, D11.2 (A_1), D11.5 (A_2), H1.1, H2.1, H3.1, H4.1, J1.7, J1.8, J1.9, J1.S1 (SHIELD), J1.S2 (SHIELD__1), J2.7, J2.8, J2.9, J2.S1 (SHIELD), J2.S2 (SHIELD__1), J3.7, J3.8, J3.9, J3.S1 (SHIELD), J3.S2 (SHIELD__1), J4.7, J4.8, J4.9, J4.S1 (SHIELD), J4.S2 (SHIELD__1), J6.6, P1.2, R3.2, R4.2, R26.1, R29.1, R30.1, R31.1, R36.1, R38.1, R40.1, R53.2, R57.2, RP1.6 (GND_1), RP1.9 (GND_2), RP1.14 (GND_3), RP1.20 (GND_4), RP1.25 (GND_5), RP1.30 (GND_6), RP1.34 (GND_7), RP1.39 (GND_8), U1.1 (AINCOM), U1.14 (DGND), U1.17 (CLK), U1.24 (REFCOM), U1.27 (AVSS), U1.28 (AVSS), U1.29 (REFN0), U1.33 (PAD), U2.1 (AINCOM), U2.14 (DGND), U2.17 (CLK), U2.24 (REFCOM), U2.27 (AVSS), U2.28 (AVSS), U2.29 (REFN0), U2.33 (PAD), U3.1 (AINCOM), U3.14 (DGND), U3.17 (CLK), U3.24 (REFCOM), U3.27 (AVSS), U3.28 (AVSS), U3.29 (REFN0), U3.33 (PAD), U4.1 (GND), U4.2 (GND), U5.1 (GND), U6.3 (GND), U7.5 (PGND), U7.6 (PGND), U7.16 (PGND), U7.17 (PGND), U7.24 (AGND), U7.27 (AGND), U7.28 (PGND), U7.29 (PGND), U7.32, U7.35, U7.36, U8.5 (PGND), U8.6 (PGND), U8.16 (PGND), U8.17 (PGND), U8.24 (AGND), U8.27 (AGND), U8.28 (PGND), U8.29 (PGND), U8.32, U8.35, U8.36, U9.5 (PGND), U9.6 (PGND), U9.16 (PGND), U9.17 (PGND), U9.24 (AGND), U9.27 (AGND), U9.28 (PGND), U9.29 (PGND), U9.32, U9.35, U9.36, U10.4 (*2OE), U10.5 (2A), U10.7 (GND), U10.15 (EPAD)
unnamed: C2.1, R6.2, U1.7 (AIN0)
unnamed: C1.1, R5.2, U1.6 (AIN1)
unnamed: C11.2, C25.1, R20.1, U1.5 (AIN2)
unnamed: C11.1, C18.1, R19.1, U1.3 (AIN4)
unnamed: C6.1, R10.2, U1.22 (GPIO0_AIN8)
unnamed: C5.1, R9.2, U1.21 (GPIO1_AIN9)
unnamed: C4.1, R8.2, U1.20 (GPIO2_AIN10)
unnamed: C3.1, R7.2, U1.19 (GPIO3_AIN11)
unnamed: C10.1, C17.1, R17.1, U1.31 (REFN1_AIN7)
unnamed: C10.2, C24.1, R18.1, U1.32 (REFP1_AIN6)
unnamed: R27.1, U1.18 (RESET_N)
unnamed: C76.1, R46.2, U2.7 (AIN0)
unnamed: C75.1, R45.2, U2.6 (AIN1)
unnamed: C86.2, C98.1, R61.1, U2.5 (AIN2)
unnamed: C86.1, C97.1, R60.1, U2.3 (AIN4)
unnamed: C83.1, R55.2, U2.22 (GPIO0_AIN8)
unnamed: C80.1, R44.2, U2.21 (GPIO1_AIN9)
unnamed: C78.1, R48.2, U2.20 (GPIO2_AIN10)
unnamed: C77.1, R47.2, U2.19 (GPIO3_AIN11)
unnamed: C85.1, C96.1, R58.1, U2.31 (REFN1_AIN7)
unnamed: C85.2, C99.1, R59.1, U2.32 (REFP1_AIN6)
unnamed: R51.1, U2.18 (RESET_N)
unnamed: C7.2, C21.1, R12.2, U3.7 (AIN0)
unnamed: C7.1, C14.1, R11.2, U3.6 (AIN1)
unnamed: C13.2, C27.1, R24.1, U3.5 (AIN2)
unnamed: C13.1, C20.1, R23.1, U3.3 (AIN4)
unnamed: C9.2, C23.1, R16.2, U3.22 (GPIO0_AIN8)
unnamed: C9.1, C16.1, R15.2, U3.21 (GPIO1_AIN9)
unnamed: C8.2, C22.1, R14.2, U3.20 (GPIO2_AIN10)
unnamed: C8.1, C15.1, R13.2, U3.19 (GPIO3_AIN11)
unnamed: C12.1, C19.1, R21.1, U3.31 (REFN1_AIN7)
unnamed: C12.2, C26.1, R22.1, U3.32 (REFP1_AIN6)
unnamed: R28.1, U3.18 (RESET_N)
unnamed: U7.20 (CBOOT), U7.21 (RBOOT)
unnamed: R32.1, U7.2 (EN/SYNC)
unnamed: R35.1, R36.2, U7.25 (FB)
unnamed: R29.2, U7.1 (RT)
unnamed: C66.1, U7.23 (VCC)
unnamed: U8.20 (CBOOT), U8.21 (RBOOT)
unnamed: R33.1, U8.2 (EN/SYNC)
unnamed: R37.1, R38.2, U8.25 (FB)
unnamed: R30.2, U8.1 (RT)
unnamed: C68.1, U8.23 (VCC)
unnamed: U9.20 (CBOOT), U9.21 (RBOOT)
unnamed: R34.1, U9.2 (EN/SYNC)
unnamed: R39.1, R40.2, U9.25 (FB)
unnamed: R31.2, U9.1 (RT)
unnamed: C67.1, U9.23 (VCC)

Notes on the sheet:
Sensors
RASPBERRY PI 4
Low Dropout Regulator
5V supply for Pi
This IC allows the Pi's full-duplex UART peripheral to talk with the half-duplex servo serial bus
Valves
***maybe drop 10Vs to 9Vs or 9.5Vs
Flow Meter Daughter Board
6V to LDO -> 5V for ADC AVDD
BUCK CONVERTERS
MOUNTING HOLES
Clean 5V supply
Clean 10V for load cell excitation
INPUT ESD and SURGE PROTECTION
11V to LDO -> 10V for Load Cell Excitation
OTHER CONNECTORS
POWER DISTRIBUTION
TOTAL SENSOR CAPABILITIES: - 12 PTs (3- or 4-wire) - 3 RTDs (3-wire) - 3 Load Cells (2x 5V, 1x 10V Excitement)
POWER
Voltage divider to step the 5V signal from the servo serial bus to a tolerable GPIO voltage (~3.33V)
ADCs AND ANALOG FRONT END
DSUB CONNECTORS
Precision Reference IC
Precision 5V Reference for ADC
UART CONVERSION

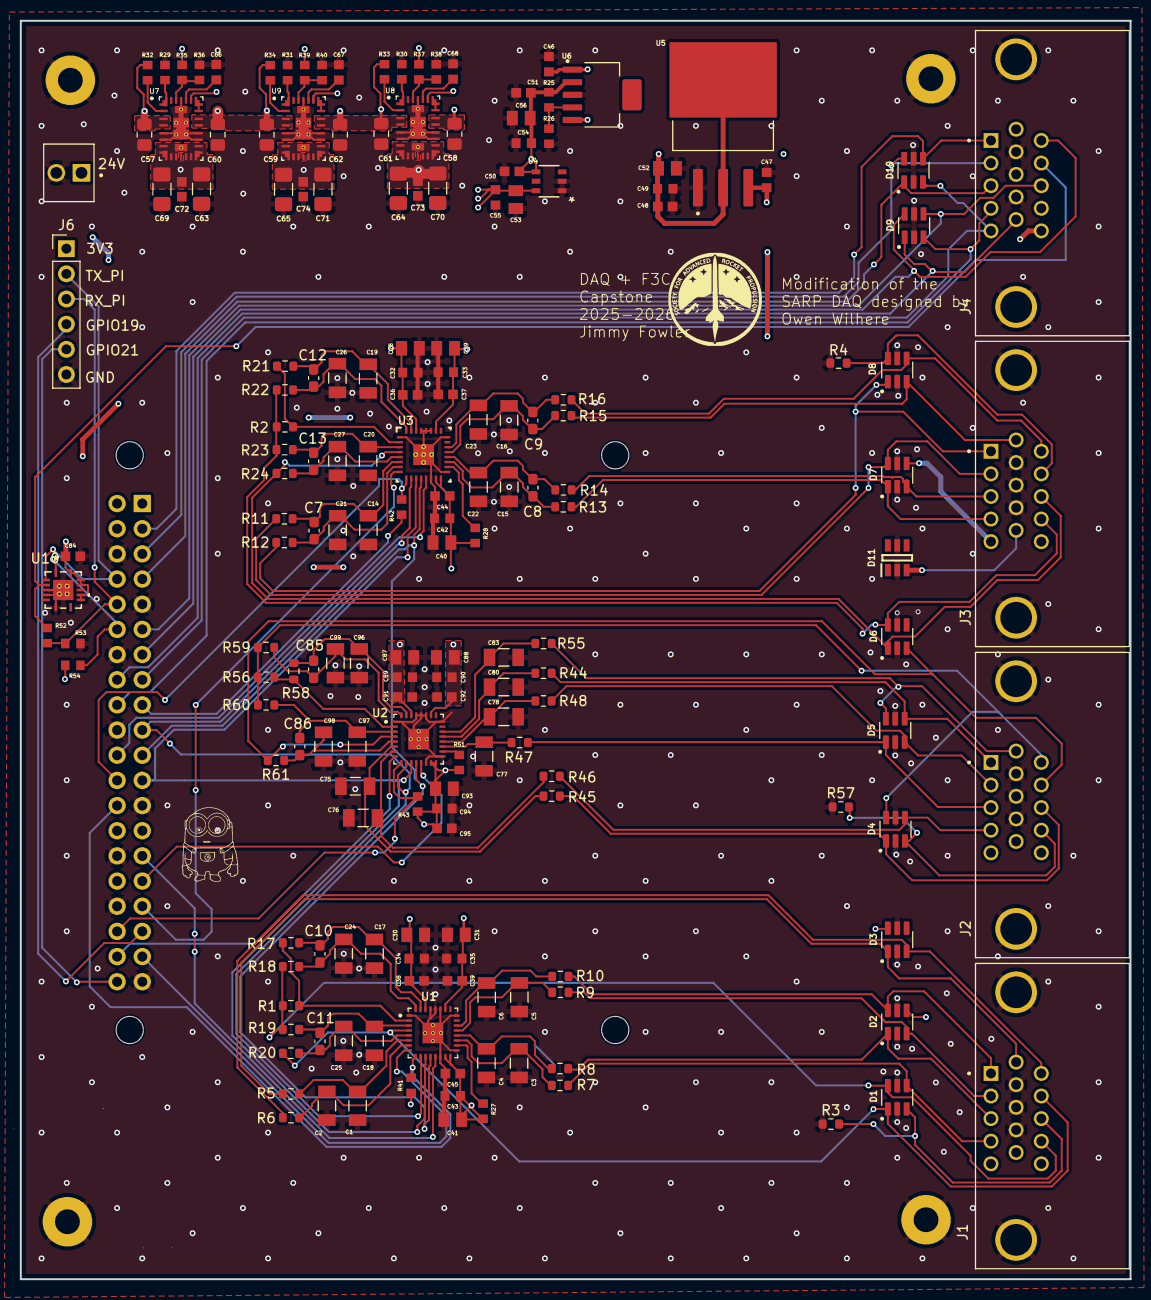
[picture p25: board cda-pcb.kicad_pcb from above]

Board: 4 copper layers, 112.0 x 127.0 mm, 187 parts (1 on the bottom side), 114 nets.

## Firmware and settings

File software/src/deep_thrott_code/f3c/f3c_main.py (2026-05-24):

try:
    import RPi.GPIO as GPIO
    import pigpio
    GPIO_AVAILABLE = True
except ModuleNotFoundError:
    GPIO_AVAILABLE = False

import time
from deep_thrott_code.f3c.controller import Controller
from queue import Queue
import threading

# single valve actuation test

test_command_queue = Queue()
test_ack_queue = Queue()

print("Initializing Controller...")
controller = Controller("test_hardware.yaml", "test_sequences.yaml", test_command_queue, test_ack_queue)
print("Controller initialized.")
controller_thread = threading.Thread(target=controller.start)
controller_thread.daemon = True
print("Starting controller thread...")
controller_thread.start()
print("Controller thread started.")

valve_id_list = ["test_valve1", "test_valve2", "test_valve3", "test_valve4", "test_valve5", "test_valve6", "test_valve7", "test_valve8"]

for valve_id in valve_id_list:
    print(f"Actuating valve {valve_id}")
    test_command_queue.put({
        "type": "set_valve",
        "valve_id": valve_id,
        "state": "open"
    })
    time.sleep(1)
    test_command_queue.put({
        "type": "set_valve",
        "valve_id": valve_id,
        "state": "closed"
    })



# print("Actuating valve 9")
# test_command_queue.put({
#     "type": "set_valve",
#     "valve_id": "test_valve9",
#     "state": "open"
# })

# time.sleep(1)
#
# print("Actuating valve 10")
# test_command_queue.put({
#     "type": "set_valve",
#     "valve_id": "test_valve10",
#     "state": "open"
# })

# print("Single valve actuation command to controller: open")
# test_command_queue.put({
#     "type": "set_valve",
#     "valve_id": "test_valve",
#     "valve_state": "open"
# })
#
# time.sleep(5)
#
# print("Single valve actuation command to controller: close")
# test_command_queue.put({
#     "type": "set_valve",
#     "valve_id": "test_valve",
#     "valve_state": "closed"
# })

time.sleep(5)

# if GPIO_AVAILABLE:
#     print("GPIO command high")
#     GPIO.output(pin, GPIO.HIGH)
#
#     time.sleep(5)
#
#     print("GPIO command low")
#     GPIO.output(pin, GPIO.LOW)
#
#     time.sleep(5)
#     GPIO.cleanup()

# time.sleep(10)

# print("Single valve actuation command to controller: pulse for 10 seconds")
# test_command_queue.put("single valve pulse", "test valve", )
# time.sleep(10)

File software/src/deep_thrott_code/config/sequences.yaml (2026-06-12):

sequences:
  - name: fill
    steps:
      - valve_id: ftvv
        action: closed
        time_delay: 0.0
        user_input: true
        system_state: fill

      - valve_id: otvv
        action: closed
        time_delay: 0.0
        user_input: true
        system_state: fill

      - valve_id: lffv
        action: open
        time_delay: 0.0
        user_input: true
        system_state: fill

      - valve_id: otvv
        action: open
        time_delay: 0.0
        user_input: true
        system_state: fill

      - valve_id: offv
        action: open
        time_delay: 0.0
        user_input: true
        system_state: fill

      - valve_id: offv
        action: closed
        time_delay: 0.0
        user_input: true
        system_state: fill

      - valve_id: otvv
        action: closed
        time_delay: 0.0
        user_input: true
        system_state: fill

      - valve_id: xffv
        action: open
        time_delay: 0.0
        user_input: true
        system_state: fill

      - valve_id: omctv
        action: open
        time_delay: 0.0
        user_input: true
        system_state: fill

      - valve_id: fmctv
        action: open
        time_delay: 0.0
        user_input: true
        system_state: fill

# coldflow sequence
  # - name: fire
  #   steps:
  #   - valve_id: otfv
  #     action: open
  #     time_delay: 0.0
  #     user_input: false
  #     system_state: fire
  
  #   - valve_id: wmv
  #     action: open
  #     time_delay: 2.0
  #     user_input: false
  #     system_state: fire

  #   - valve_id: omv
  #     action: open
  #     time_delay: 0.0
  #     user_input: false
  #     system_state: fire

  #   - valve_id: fmv
  #     action: open
  #     time_delay: 4.0
  #     user_input: false
  #     system_state: fire

  #   - valve_id: fmctv
  #     action: throttle
  #     angle: 75.0
  #     time: 1.0
  #     time_delay: 0.0
  #     user_input: false
  #     system_state: fire

  #   - valve_id: omctv
  #     action: throttle
  #     angle: 75.0
  #     time: 2.0
  #     time_delay: 4.0
  #     user_input: false
  #     system_state: fire

  #   - valve_id: fifv
  #     action: open
  #     time_delay: 0.0
  #     user_input: true
  #     system_state: fire

  #   - valve_id: oifv
  #     action: open
  #     time_delay: 0.0
  #     user_input: true
  #     system_state: fire
      
  #   - valve_id: lffv
  #     action: closed
  #     time_delay: 0.0
  #     user_input: true
  #     system_state: fire

  #   - valve_id: xffv
  #     action: closed
  #     time_delay: 0.0
  #     user_input: true
  #     system_state: fire

    #  - valve_id: fmctv
    #    action: throttle
    #    angle: 45.0
    #    time: 0.5
    #    time_delay: 0.0
    #    user_input: false
    #    system_state: fire

    #  - valve_id: omctv
    #    action: throttle
    #    angle: 45.0
    #    time: 0.5
    #    time_delay: 4.0
    #    user_input: false
    #    system_state: fire

    #  - valve_id: lffv
    #    action: closed
    #    time_delay: 0.0
    #    user_input: false
    #    system_state: fire

    #  - valve_id: fifv
    #    action: closed
    #    time_delay: 0.0
    #    user_input: false
    #    system_state: fire

    #  - valve_id: xffv
    #    action: closed
    #    time_delay: 0.0
    #    user_input: true
    #    system_state: fire

# # igniter sequence
#   - name: fire
#     steps:
#       - valve_id: wmv
#         action: open
#         time_delay: 0.0
#         user_input: false
#         system_state: fire
    
#       - valve_id: otfv
#         action: open
#         time_delay: 4.0
#         user_input: false
#         system_state: fire

#       - valve_id: oifv
#         action: open
#         time_delay: 0.1
#         user_input: false
#         system_state: fire
      
#       - valve_id: fifv
#         action: open
#         time_delay: 6.0
#         user_input: false
#         system_state: fire

#       - valve_id: omv
#         action: open
#         time_delay: 0.0
#         user_input: false
#         system_state: fire

#       - valve_id: otvv
#         action: open
#         time_delay: 2.0
#         user_input: false
#         system_state: fire

#       - valve_id: lffv
#         action: closed
#         time_delay: 0.0
#         user_input: true
#         system_state: fire

#       - valve_id: xffv
#         action: closed
#         time_delay: 0.0
#         user_input: true
#         system_state: fire

#       - valve_id: oifv
#         action: closed
#         time_delay: 0.0
#         user_input: true
#         system_state: fire

   #    system_state: fire

# # igniter sequence backup
#   - name: fire
#     steps:
#       - valve_id: wmv
#         action: open
#         time_delay: 0.0
#         user_input: false
#         system_state: fire
    
#       - valve_id: otfv
#         action: open
#         time_delay: 4.0
#         user_input: false
#         system_state: fire
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

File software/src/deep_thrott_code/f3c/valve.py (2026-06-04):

from __future__ import annotations

from enum import Enum
import time
import threading

from scipy.stats import false_discovery_control

# import serial

try:
    import pigpio  # type: ignore
    import RPi.GPIO as GPIO
    GPIO_AVAILABLE = True

    # Ensure GPIO numbering mode is configured once.
    # We use BCM numbering, so `hardware.yml` pins should be BCM GPIO numbers.
    try:
        GPIO.setwarnings(False)
        GPIO.setmode(GPIO.BCM)
    except Exception as exc:
        # Don't force simulation mode here; let setup/output attempts surface
        # the real error (usually permissions) with explicit prints.
        print(f"GPIO init (setmode BCM) failed: {exc!r}")
except ModuleNotFoundError:
    # Windows/dev-machine friendly stub.
    # On non-Pi systems we still want to import and run the controller in
    # "simulation" without touching GPIO.
    GPIO_AVAILABLE = False

computer_sim = False

if computer_sim:
    GPIO_AVAILABLE = False

class ValveState(Enum):
    """
    Defines the states a valve can be in.
    """
    CLOSED = "closed"
    OPEN = "open"
    THROTTLING = "throttling"

class Valve:
    """
    Class which represents an on/off valve, parent for throttle valves.
    """

    def __init__(self, valve_id: str, pin: int | None, normally_closed: bool):
        self.valve_id = valve_id
        self.pin = pin
        self.normally_closed = normally_closed
        self.default_state = ValveState.CLOSED if normally_closed else ValveState.OPEN
        self.state = self.default_state
        # Only touch GPIO when available and wired.
        if GPIO_AVAILABLE and self.pin is not None:
            try:
                GPIO.setup(self.pin, GPIO.OUT, initial=GPIO.LOW)
            except Exception:
                # Best-effort: keep simulation runnable.
                pass
            except Exception as exc:
                print(f"GPIO setup failed for valve {self.valve_id} on pin {self.pin}: {exc!r}")
        elif self.pin is None:
            print(f"Valve {self.valve_id}: pin is None (not wired/configured)")
        elif not GPIO_AVAILABLE:
            print(f"Valve {self.valve_id}: RPi.GPIO unavailable; running in simulation mode")

    def get_valve_id(self) -> str:
        return self.valve_id

    def get_state(self) -> ValveState:
        return self.state

    def is_normally_closed(self) -> bool:
        return self.normally_closed

    def set_state(self, new_state: ValveState):
        if self.state != new_state:
            self.state = new_state
            if GPIO_AVAILABLE and self.pin is not None:
                try:
                    if new_state == ValveState.OPEN:
                        level = GPIO.HIGH if self.normally_closed else GPIO.LOW
                    else:
                        level = GPIO.LOW if self.normally_closed else GPIO.HIGH
                    GPIO.output(self.pin, level)
                    print(
                        f"GPIO output valve {self.valve_id} pin {self.pin} -> "
                        f"{'HIGH' if level else 'LOW'} ({new_state.value})"
                    )
                except Exception as exc:
                    print(
                        f"GPIO output failed for valve {self.valve_id} on pin {self.pin} "
                        f"(requested {new_state.value}): {exc!r}"
                    )
            else:
                # for when no rasp pi is connected, print statements instead of GPIO outputs
                if new_state == ValveState.OPEN:
                    print(f"Valve {self.valve_id} is open")
                else:
                    print(f"Valve {self.valve_id} is closed")

    def pulse_valve(self, dt: float):
        if self.state == ValveState.CLOSED:
            self.set_state(ValveState.OPEN)
            time.sleep(dt)
            self.set_state(ValveState.CLOSED)
        else:
            # TODO: send error that valve must be closed to pulse it
            pass

# TODO: add to initialization to set valve to normal state

class ThrottleValve():
    """
    Class which represents a throttleable valve.
    """
    # TODO: add command numbers/lengths from hiwonder datasheet to get rid of magic numbers
    # variables for pin setup for uart
    TX_ENABLE_PIN = 20
    TX_PIN = 14
    RX_PIN = 15
    BAUD = 115200

    # variables from Hiwonder servo bus communication protocol datasheet
    SERVO_MOVE_TIME_WRITE_CMD = 1
    SERVO_MOVE_TIME_WRITE_LEN = 7
    SERVO_POS_READ_CMD = 28
    SERVO_POS_READ_LEN = 3
    SERVO_LOAD_OR_UNLOAD_WRITE_CMD = 31
    SERVO_LOAD_OR_UNLOAD_WRITE_LEN = 4
    SERVO_LOAD_OR_UNLOAD_WRITE_PARAM = 1

    # servo units -> angle conversion values
    SERVO_ANGLE_DEG = 240
    SERVO_ANGLE_PARAM = 1000

    # lock for sending waveforms
    _wave_lock = threading.Lock()

    def __init__(self, valve_id: str, uart_id: int, serial_handle, pi_instance, normally_closed: bool):
        self.valve_id = valve_id
        self.uart_id = uart_id
        self.pi = pi_instance
        self.serial_handle = serial_handle
        self.load_motor()
        self.checksum_found = False
        self.state = ValveState.OPEN
        self.normally_closed = normally_closed


    def is_normally_closed(self) -> bool:
        return self.normally_closed

    def get_valve_id(self) -> str:
        return self.valve_id

    def get_state(self) -> ValveState:
        return self.state

    def set_state(self, new_state: ValveState, theta: float | None = None):
        actuation_time = 0
        if self.state != new_state:
            self.state = new_state

            # angles calibrated for omctv
            if self.valve_id == "omctv":
                if new_state == ValveState.CLOSED:
                    self.throttle(0, actuation_time)
                else:
                    self.throttle(90.0, actuation_time)
            # angles calibrated for fmctv
            else:
                if new_state == ValveState.CLOSED:
                    self.throttle(0, actuation_time)
                else:
                    self.throttle(90.0, actuation_time)

    def pulse_valve(self, dt: float):
        if self.state == ValveState.CLOSED:
            self.set_state(ValveState.OPEN)
            time.sleep(dt)
            self.set_state(ValveState.CLOSED)
        else:
            # TO DO: send error that valve must be closed to pulse it
            pass

    # TODO: make time_s 0.0 by default
    def throttle(self, angle_deg: float, time_s):
        """
            Move servo to angle (0-1000 => 0-240°) over time_ms (0-30000ms).
            Moves immediately on receipt.
            Implementation of SERVO_MOVE_TIME_WRITE
            """
        print(f"Throttling {self.valve_id}")

        # adjust throttle angle based on angle calibration
        if self.valve_id == "omctv":
            angle_deg = angle_deg + 73.0
        else:
            angle_deg = angle_deg + 110.0
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

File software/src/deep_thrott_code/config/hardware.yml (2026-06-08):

schema_version: 1

adcs:
  ADC1:
    model: ADS124S08IRHBT
    transport: spi
    spi_bus: 0
    spi_device: 0
    # Optional (tuning): SPI clock for this ADC (Hz)
    spi_max_speed_hz: 4000000
    # Optional (tuning): force ADS124S08 data rate (choose one)
    # - datarate_sps: desired conversions/sec (rounded up to supported setting)
    # - datarate_dr: raw DR[3:0] register code (0..15)
    datarate_sps: 2000
    # datarate_dr: 12
    # Manual CS (any free GPIO). If set, the driver uses `spi.no_cs = True` and toggles this GPIO.
    # NOTE: this only works if ADC1's CS pin is physically wired to this GPIO (not CE0).
    cs_gpio: 8
    drdy_gpio: 25
    # START/SYNC is not software-controlled in this setup; hold the ADC pin HIGH in hardware.
    start_sync_gpio: null
    notes: "ADC #1"

  ADC2:
    model: ADS124S08IRHBT
    transport: spi
    spi_bus: 0
    spi_device: 1
    spi_max_speed_hz: 4000000
    datarate_sps: 2000
    # datarate_dr: 12
    # Use hardware CE1 (GPIO7) via spi_device: 1
    cs_gpio: 7
    drdy_gpio: 5
    # START/SYNC is not software-controlled in this setup; hold the ADC pin HIGH in hardware.
    start_sync_gpio: null
    notes: "ADC #2"

  ADC3:
    model: ADS124S08IRHBT
    transport: spi
    spi_bus: 0
    spi_device: 0
    spi_max_speed_hz: 4000000
    datarate_sps: 2000
    # datarate_dr: 12
    cs_gpio: 16
    drdy_gpio: 6
    # START/SYNC is not software-controlled in this setup; hold the ADC pin HIGH in hardware.
    start_sync_gpio: null
    notes: "ADC #3"

sensors:
  hotfire:
    pressure_transducers:
      LF-PT:
        enabled: true
        adc_id: ADC2
        signal_mode: single_ended
        pt_num: 1
        ain: 1
        sampling_rate_hz: 25
        notes: "L Fuel pressure transducer"

      FT-PT:
        enabled: true
        adc_id: ADC2
        signal_mode: single_ended
        ain: 0
        pt_num: 2
        sampling_rate_hz: 25
        notes: "Fuel tank pressure transducer"

      OM-PT:
        enabled: true
        adc_id: ADC2
        signal_mode: single_ended
        ain: 8
        pt_num: 6
        sampling_rate_hz: 150
        notes: "Fuel main pressure transducer"

      FI-PT:
        enabled: true
        adc_id: ADC3
        signal_mode: single_ended
        ain: 0
        pt_num: 8
        sampling_rate_hz: 150
        notes: "Fuel injector pressure transducer"

      WM-PT:
        enabled: true
        adc_id: ADC3
        signal_mode: single_ended
        ain: 9
        pt_num: 11
        sampling_rate_hz: 25
        notes: "Water main pressure transducer"

      CC-PT:
        enabled: true
        adc_id: ADC1
        signal_mode: single_ended
        ain: 8
        pt_num: 10
        sampling_rate_hz: 150
        notes: "Combustion chamber pressure transducer"

      XF-PT:
        enabled: true
        adc_id: ADC2
        signal_mode: single_ended
        ain: 11
        pt_num: 3
        sampling_rate_hz: 25
        notes: "XF pressure transducer"

      OT-PT:
        enabled: true
        adc_id: ADC2
        signal_mode: single_ended
        ain: 9
        pt_num: 5
        sampling_rate_hz: 25
        notes: "Ox tank pressure transducer"

      OF-PT:
        enabled: true
        adc_id: ADC2
        signal_mode: single_ended
        ain: 10
        pt_num: 4
        sampling_rate_hz: 25
        notes: "Ox fill pressure transducer"

      FM-PT:
        enabled: true
        adc_id: ADC3
        signal_mode: single_ended
        ain: 1
        pt_num: 7
        sampling_rate_hz: 150
        notes: "Ox main pressure transducer"

      OI-PT:
        enabled: true
        adc_id: ADC3
        signal_mode: single_ended
        ain: 11
        pt_num: 9
        sampling_rate_hz: 150
        notes: "Ox injector pressure transducer"

    resistive temperature detectors:
      WI-RTD:
        enabled: false
        adc_id: ADC1
        signal_mode: rtd_3_wire
        lead1_ain: 4
        lead2_ain: 2
        idac1_ain: 5
        idac2_ain: 3
        adc_gain: 2
        sampling_rate_hz: 5
        notes: "Water inlet RTD"

      WO-RTD:
        enabled: false
        adc_id: ADC3
        signal_mode: rtd_3_wire
        lead1_ain: 4
        lead2_ain: 2
        idac1_ain: 5
        idac2_ain: 3
        adc_gain: 2
        sampling_rate_hz: 5
        notes: "Water outlet RTD"

      NT-RTD:
        enabled: false
        adc_id: ADC2
        signal_mode: rtd_3_wire
        lead1_ain: 4
        lead2_ain: 2
        idac1_ain: 5
        idac2_ain: 3
        adc_gain: 2
        sampling_rate_hz: 5
        notes: "Nitrous tank RTD"

    load cells:
      N-LC:
        enabled: true
        adc_id: ADC1
        signal_mode: differential
        ain_pos: 1
        ain_neg: 0
        # Optional: ADS124S08 PGA gain (1,2,4,8,16,32,64,128)
        adc_gain: 64
        sampling_rate_hz: 25
        notes: "Nitrous tank load cell"
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

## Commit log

2026-03-04 moved all software into software folder and added hardware folder for DAQ design
    [0022272021.step, 10090929-S154VLF.step, ADS1258IRTCT.step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]
2026-03-04 removed DNP mark on symbols
    [DAQ.kicad_sch]
2026-03-11 added background color to symbols
    [DAQ.kicad_sch]
2026-03-11 added labels for Bucks and LDOs
    [DAQ.kicad_sch]
2026-03-11 made the schematic look a lot prettyeiry
    [DAQ.kicad_sch]
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2026-03-14 added an ADC to schematic and started absolutely destroying the layout
    [DAQ.kicad_pcb, DAQ.kicad_sch]
2026-03-14 last commit before I replace the 15-pin DSUBs with 26-pin
    [DAQ.kicad_pcb]
2026-03-14 checking out 26pin, having footprint library issues yay
    [DAQ.kicad_pcb, DAQ.kicad_sch, ICD26S13E4GX00LF.step]
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2026-03-16 made pressure units Pa, added correct values for our system
2026-03-16 Allocated Pi GPIO to valves
    [DAQ.kicad_sch]
2026-03-18 added SH74AHCT125 to schem for uart comms with servo
    [DAQ.kicad_sch]
2026-03-19 FIXED ALL OF THE STUPID FOOTPRINT ISSUES
    [ADS124S08IRHBT.step, DAQ.kicad_pcb, DAQ.kicad_sch]
2026-03-19 starting to place 3rd ADC components
    [DAQ.kicad_pcb, DAQ.kicad_sch]
2026-04-01 moved daq src to correct folder
    [adc.py, hardware.py]
2026-04-01 last commit before redoing dsub pinouts
    [DAQ.kicad_sch]
2026-04-02 lowkirk idk what I changed but I want to start working on my pc
    [DAQ.kicad_pcb]
2026-04-02 re-mapped all DSUB pins
    [DAQ.kicad_pcb, DAQ.kicad_sch, DB25-SL-25.step]
2026-04-02 completed 15-pin DSUB pinouts
    [DAQ.kicad_pcb, DAQ.kicad_sch]
2026-04-03 properly dimensioned edge cuts and mounting holes
    [DAQ.kicad_pcb]
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2026-04-04 I don't think I did anything lowkey
    [DAQ.kicad_sch]
2026-04-04 starting to clear ERCs, next will try to fit a third RTD
    [DAQ.kicad_pcb, DAQ.kicad_sch]
2026-04-04 added 3rd RTD to ADC3 and added some PWR FLAGs for ERCs
    [DAQ.kicad_sch]
2026-04-04 changed stackup to 4 copper layers
    [DAQ.kicad_pcb, DAQ.kicad_sch]
2026-04-05 more ERC fixes
    [DAQ.kicad_sch]
2026-04-05 updated layout with new ESD components w/ no errors
    [DAQ.kicad_pcb, DAQ.kicad_sch]
2026-04-05 lined up all ESD ICs, need to reorganize ESD/DSUB pins
    [DAQ.kicad_pcb]
2026-04-05 almost finished arranging ADC3 components
    [DAQ.kicad_pcb]
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2026-04-08 routed UART conversion components
    [DAQ.kicad_pcb, DAQ.kicad_sch]
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2026-04-12 routed valve actuation traces thu TVS and GPIO
    [DAQ.kicad_pcb, DAQ.kicad_sch]
2026-04-12 reordered references and started power traces
    [DAQ.kicad_pcb, DAQ.kicad_sch]
2026-04-12 rearanged components in schematic
    [DAQ.kicad_pcb, DAQ.kicad_sch]
2026-04-13 3/4 DSUBs routed >:)
    [DAQ.kicad_pcb, DAQ.kicad_sch]
2026-04-13 change name to cda-pcb (control and data acquisition)
    [0022272021.step, 10090929-S154VLF.step, ADS124S08IRHBT.step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]
2026-04-13 EVERYTHING IS ROUTED RRAHHHH
    [cda-pcb.kicad_pcb, cda-pcb.kicad_sch]
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2026-04-13 potentially done with DRC
    [cda-pcb.kicad_pcb]
2026-04-13 changes for ease of assembly
    [cda-pcb.kicad_pcb]
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2026-04-13 changed inner copper layers to 0.5oz
    Remove two old backup zips and add two new backups. Adjust PCB stackup in cda-pcb.kicad_pcb: reduce copper thickness for In1.Cu and In2.Cu from 0.035 to 0.017 and tweak dielectric 2 thickness from 1.24 to 1.276. Change active_layer to 0 in cda-pcb.kicad_prl. Clean up numerous DRC exclusions in cda-pcb.kicad_pro and set hole_clearance from "error" to "ignore".
    [cda-pcb.kicad_pcb]
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2026-04-15 add fiducials, remove handsoldered footprints, added indicator LEDs
    Add board backups and make multiple PCB/schematic edits: adjust fiducial positions, add a new via, and tweak component and label coordinates for alignment. Add several schematic symbols and instances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
    [cda-pcb.kicad_pcb, cda-pcb.kicad_sch]
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2026-04-15 addfed stitching vias
    Modify PCB to add numerous free vias (mostly on net 2/GND) and refresh UUIDs for multiple pads/power pins. Updated cda-pcb.kicad_pcb with many new via entries and coordinate adjustments; supporting K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
    [cda-pcb.kicad_pcb, cda-pcb.kicad_sch]
2026-04-16 changed 10Vs buck output to be 9.988V and added a 2nd 10Vs dsub pin
    [cda-pcb.kicad_pcb, cda-pcb.kicad_sch]
2026-04-16 started on simulated sensor input test w copilot
    [daq_test_log.csv]
2026-04-16 finished back soldermask, re-added stitching vias, made gerbs
    [436500227.stp, cda-pcb-rev2_bom.csv, cda-pcb-rev2_designators.csv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]
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2026-04-21 crazy Pc oscillations
    added saturation on delta P in all valves and injector blocks which caused this behavior
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2026-04-25 daq main moved to actual main, started skeleton
    [daq_log.csv]
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2026-04-28 fixed socketio connect errors, updated pid
    [daq_gui_log.csv]
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2026-04-29 valve updates
    Updated actuator components in hardware config to include all valves with some edits to existing valve info
    [hardware.yml]
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2026-04-29 active_high valve edits
    Fixed active_high definitions on valves
    [hardware.yml]
2026-04-29 added threading and sequencing logic
    Put the _loop() method in a thread and started to add transition logic in _execute_action(). Fixed syntax errors in _build_sequences
    [controller.py]
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2026-04-29 deleted driver field
    Got rid of driver field from all actuators (meaning duplicated in mode field)
    [hardware.yml]
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2026-04-29 added sequencing in _execute_action()
    The basic functionality of fill and fire sequencing in the _execute_action() method was completed with state validation (no error handling yet), time delays, and user input capability.
    [controller.py]
2026-04-30 updated queues, abort, and single valve
    Corrected queues in controller.py and added placeholders for functionality to handle aborts and single valve actuations. Also restructured _execute_action() state validation slightly
    [controller.py]
2026-04-30 igniter valve updates
    Updated igniter valves to be nominally closed (switched physical valves from NO to NC)
    [hardware.yml]
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2026-05-04 make lookup table files, get rid of combustion delay in chamebr
    [cstar_lookup_table.xlsx, sonvel_lookup_table.xlsx]
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2026-05-05 Update controller.py
    Minor fixes, added single valve actuation placeholder
    [controller.py]
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2026-05-05 main try/excepts for f3c to run daq sim
    [daq_backend_log.csv]
2026-05-05 single valve actuation test w/controller
    Setting up f3c test main for single valve actuation test using controller methods. Also adding a test_hardware config file to use for controller test. Set valve to be default low
    [test_hardware.yaml]
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2026-05-05 config file implementation fixes
    [controller.py, f3c_main.py]
2026-05-05 fixing valve list building method
    [controller.py]
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2026-05-05 small controller refactor + bug fix
    [controller.py]
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2026-05-06 adc bug fix
2026-05-06 timeout error handling daq
    [adc.py]
2026-05-06 controller threading, added back fill
    Added fill sequence functionality back to controller. Added threading in _execute_action so all calls to execute action begin in a separate thread so the loop in start() doesn't get stopped. Also added pulse valve functionality and implemented some gui integration stuff.
    [controller.py]
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2026-05-06 f3c main gpio import error handling
    [f3c_main.py]
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2026-05-07 fixing ThrottleValve import bug
    [servo_chirp.py]
2026-05-07 serial port bug fix
    [servo_chirp.py]
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2026-05-07 uart bug fixes
2026-05-07 deleted hardware reset from test program
    [adc_smoke_test.py]
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2026-05-08 fixed test valve initialization call
    [servo_chirp.py]
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2026-05-08 reset input buffer fix
    [servo_chirp.py]
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2026-05-08 disabled some valves and throttle, f3 gui integration testing
    [hardware.yml]
2026-05-08 add epsilon soft clamp in all pressure sats
    avoid piecewise functions of pressure so that algebraic loop can solve hopefully
2026-05-08 testing bug fixes
    [hardware.yml]
2026-05-08 werkzeug fix and gpio permis fix
    [valve.py]
2026-05-08 fix units on a and cstar lookup table pressures
    Pa instead of psi
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2026-05-11 added injector and valve isolation testing files, commented main file with success in testing
    [cstar_lookup_table.xlsx, sonvel_lookup_table.xlsx]
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2026-05-11 fixed tx_enable pin, added prints for debugging
    [servo_chirp.py, valve.py]
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2026-05-12 remove mdot leak term, testing with servo, valve, inj, chamber
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2026-05-19 commented out servos and added pin nums for testing
    [hardware.yml]
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2026-05-19 get_state() missing ref fix
    [controller.py]
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2026-05-19 valve naming correct
    [hardware.yml]
2026-05-19 fixed default state
    [hardware.yml]
2026-05-19 switched omw and otvv gpio nums to test
    [hardware.yml]
2026-05-19 gpio fix
    [hardware.yml]
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2026-05-19 100 hz sample, updated injector cold flow hardware pins
    [hardware.yml]
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2026-05-20 adc timing fixes
    [hardware.yml]
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2026-05-21 DRDY1 REVERT
    [hardware.yml]
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2026-05-21 read response echo robust fix
    [valve.py]
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2026-05-21 get rid of condition valves, fix fill
    [sequences.yaml]
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2026-05-22 adc fix
    [hardware.yml]
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2026-05-22 corrected gpio on test program
    [test_manual_cs.py]
2026-05-22 cs fix to adc class + initialization in sensors
    [adc.py, sensors.py, test_manual_cs.py]
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2026-05-22 dropping sample fix
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2026-05-22 dropping sample fix again
    [adc.py, sensors.py]
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2026-05-23 fix valve import
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2026-05-23 relay test pin numbering + misc fixes
    [test_hardware.yaml]
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2026-05-24 gui fixes
    [hardware.yml]
2026-05-24 pid tab fix
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2026-05-24 pid shrink issue
2026-05-24 pid shrink issue trying to fix
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2026-05-25 refrehs error and daq button height change
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2026-05-25 swapped LS3 for FM1 & FM2 signals on ADC
    [cda-pcb.kicad_sch]
2026-05-25 flow meter + button fix
    [conversions.yml, sensors.py]
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2026-05-25 producer sampling rate fix
    [hardware.yml]
2026-05-25 cache fix
    [hardware.yml]
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2026-05-25 threading fix
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2026-05-26 drdy change reverted + increased multiplier
    [adc.py]
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2026-05-26 disabled some slow sensors again to compare noise
    [hardware.yml]
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2026-05-26 igniter valve fixes
    [hardware.yml]
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2026-05-26 more attempts to fix RTDs
    [hardware.yml]
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2026-05-26 more rtd fixes
    [hardware.yml]
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2026-05-26 main shutdown + more rtd fix
    [sensors.py]
2026-05-26 pwm arg fix
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2026-05-26 fix pwm import
2026-05-26 fix pwm args
2026-05-26 fix throttle servo args
    [servo_chirp.py]
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2026-05-27 fixing state updates in sequence
    [controller.py]
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2026-05-30 rtd testing config + flow meter data analysis
    [hardware.yml]
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2026-06-01 Revert "throttle calibration"
    This reverts commit 1dcbe17287cd1101a11d33deecc6e0f047c13ac3.
    [valve.py]
2026-06-01 Revert "coldflow sequence throttle steps"
    This reverts commit abe15b03e85f8c94de44c110afdfde07a9664a84.
    [sequences.yaml]
2026-06-01 Revert "pass tx_enable_pin into throttlevalve"
    This reverts commit 5317354fd0e7837093d4608796a20e48c0210dfb.
    [controller.py]
2026-06-01 Reapply "coldflow sequence throttle steps"
    This reverts commit e5e59b072ab9cc5fa9cf711bc920824abcc58827.
    [sequences.yaml]
2026-06-01 Reapply "throttle calibration"
    This reverts commit 39c61915a4ad1abf2cf355938f29eb06ffdd8928.
    [valve.py]
2026-06-01 Revert "unhardcode tx_enable_pin"
    This reverts commit ea7cef960d10b26dfe56329034ef71d317f5e337.
    [valve.py]
2026-06-01 Revert "Reapply "throttle calibration""
    This reverts commit bec56f1b42413d15a2f0bcf2559fcf8e9655842c.
    [valve.py]
2026-06-01 Revert "Reapply "coldflow sequence throttle steps""
    This reverts commit 8a42bccd5f199753e4f32f1cd5f13b9e9f53d689.
    [sequences.yaml]
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2026-06-02 servo angle fix
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2026-06-02 PT 6 and 7 swap, xf-pt range update
    [hardware.yml]
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2026-06-03 lfpt and xfpt swap
    [conversions.yml]
2026-06-03 accidentally swapped to ccpt last commit
    [conversions.yml]
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2026-06-03 omctv angle calib fix
    [valve.py]
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2026-06-05 changed throttle handling in sequencing and fixed a default closed action
    [controller.py, sequences.yaml]
2026-06-05 fixed print statement
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2026-06-08 sampling rate fix
    [hardware.yml]
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2026-06-11 fix cold flow indents
    [sequences.yaml]
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2026-06-11 cold flow 2 data analysis update + sequence yaml bug fix
    [sequences.yaml]
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
